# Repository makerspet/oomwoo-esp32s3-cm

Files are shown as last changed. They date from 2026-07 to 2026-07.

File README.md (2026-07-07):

# oomwoo-esp32s3-cm

Spec TBD; Not decided if we need this or not.

Pi CM4/CM5-compatible Compute Module using ESP32-S3 instead of CPU

Purpose - cost reduced "educational" version of OOMWOO open-source vacuum cleaner
robot by replacing Pi CM4/CM5 with ESP32-S3, moving mapping/navigation compute to
a separate local PC running ROS2.

Tradeoffs:
- this is not a "consumer product" anymore due to the need to set up the additional ROS2 local PC
  - PC-to-ESP32-S3 Wi-Fi connection can suffer from dead reception zones, busy Wi-Fi
- no camera-based obstacle recognition

- mounts on [OOMWOO carrier I/O board](https://github.com/makerspet/oomwoo-io-board)
- pin-compatible CM4/CM5 Compute Module using ESP32-S3 (instead of CPU)
- expose GPIOs on CM4/CM5 headers
  - 1x serial to MCU
  - GPIOs (MCU acts as watchdog for ESP32-S3, can reset it if ESP32-S3 is unresponsive)
  - SPI (to IMU on I/O board)
  - I2C
  - 1x serial to LiDAR (via I/O board)
- Problem - no cameras, ESP32-S3 supports DVP parallel only, not MIPI

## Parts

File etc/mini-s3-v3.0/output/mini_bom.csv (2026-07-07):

Comment | Designator | Footprint | LCSC Part Number
0603B151K500NT | C14,C15,C16,C17,C26,C37 | C0603 | C1594
SS8050_C2150 | Q2,Q3 | SOT-23-3_L2.9-W1.3-P1.90-LS2.4-BR | C2150
KT-0603R | LED1 | LED0603-RD | C2286
KT-0603W | LED2 | LED0603-R-RD_WHITE | C2290
AMS1117-3.3 | U8 | SOT-223-3_L6.5-W3.4-P2.30-LS7.0-BR | C6186
CC0603KRX7R9BB104 | C1,C3,C18,C19,C21,C22,C23,C27 | C0603 | C14663
AO3401A | Q1 | SOT-23_L2.9-W1.3-P1.90-LS2.4-BR | C15127
CL10B223KB8NNNC | C10,C11 | C0603 | C21122
0603WAF0000T5E | R31,R32 | R0603 | C21189
0603WAF1000T5E | R3 | R0603 | C22775
0603WAF2702T5E | R6 | R0603 | C22967
0603WAF5100T5E | R1,R2,R10,R18,R19,R22,R23,R26,R27,R28,R30 | R0603 | C23193
0603WAF9102T5E | R15 | R0603 | C23265
0603WAF1002T5E | R4,R5,R7,R8,R9,R11,R12,R20,R21,R24,R25,R29,R40 | R0603 | C25804
0603WAF1103T5E | R13,R16,R17 | R0603 | C25805
CL21A226MAQNNNE | C8,C12 | C0805 | C45783
CL10A226MP8NUNE | C2,C4,C7,C9,C13,C24,C25 | C0603 | C86295
MT2492 | U4,U5 | SOT-23-6_L2.9-W1.6-P0.95-LS2.8-BL | C89358
ZH1.5-6A M | J4,J7 | CONN-TH_6P-P1.50_ZH1.5-6A | C146013
FNR4030S100MT | L1,L2 | IND-SMD_L4.0-W4.0_FNR40XXS | C167879
1N5819WS | D1,D2,D3 | SOD-323_L1.8-W1.3-LS2.5-RD | C191023
TS-1187A-B-A-B | SW2,SW3 | SW-SMD_4P-L5.1-W5.1-P3.70-LS6.5-TL-2 | C318884
AECR0603F15K0K9 | R14 | R0603 | C328339
SK12D07VG5 | SW1 | SW-TH_SK12D07VG5 | C431548
ESP32-S3-WROOM-1-N4 | U3 | WIFIM-SMD_ESP32-S3-WROOM-1-N8 | C2913197
USB-MR-D-015 | U7,U9 | MICRO-USB-SMD_920-C52A2021S10105 | C2926986
BDR6120H | U1,U2 | SOP-8_L4.9-W3.8-P1.27-LS6.0-BL | C3007876
1.25-4PLTDK | J13 | CONN-SMD_4P-P1.25_SHOU_1.25-4PLTDK | C3008549
MX250-3.5-02P-B-GY01-CU-A | J2 | CONN-TH_2P-MX250-3.5-02P-B-GY01-CU-A | C7470116
CH340K_C18208922 | U6 | ESOP-10_L4.9-W3.9-P1.00-LS6.0-BL-EP | C18208922

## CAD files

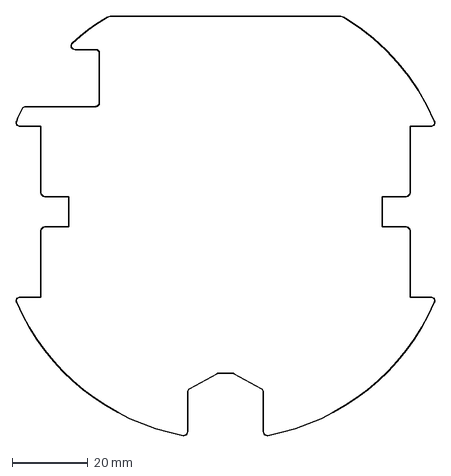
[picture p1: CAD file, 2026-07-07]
etc/mini-s3-v3.0/pcb_cutout.dxf
110.3 x 110.5 mm

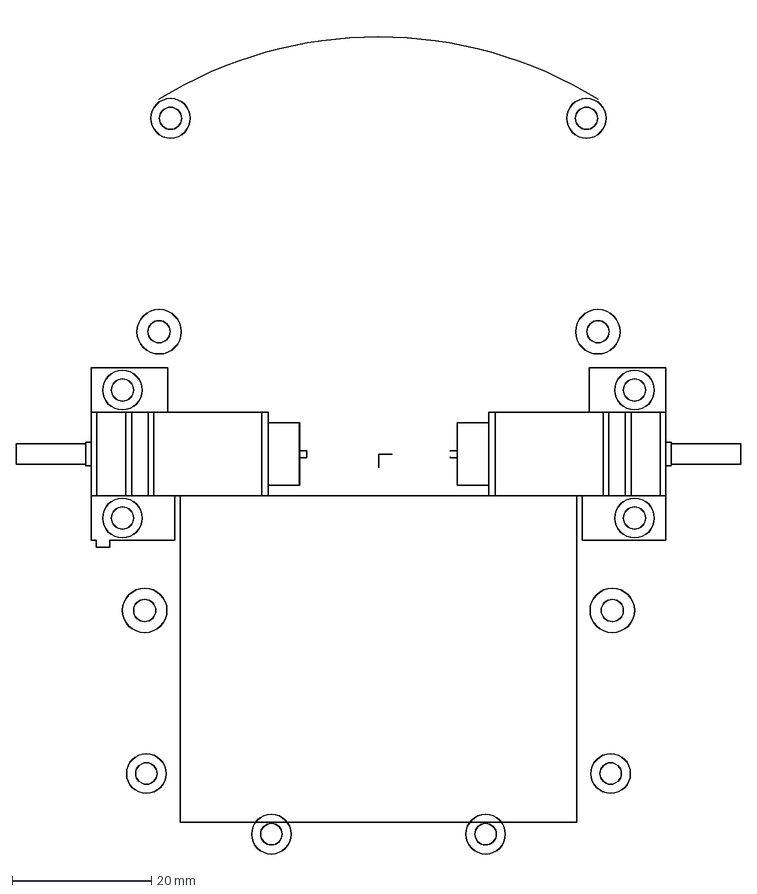
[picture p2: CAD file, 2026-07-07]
etc/mini-s3-v3.0/pcb_placement.dxf
104.2 x 120.5 mm

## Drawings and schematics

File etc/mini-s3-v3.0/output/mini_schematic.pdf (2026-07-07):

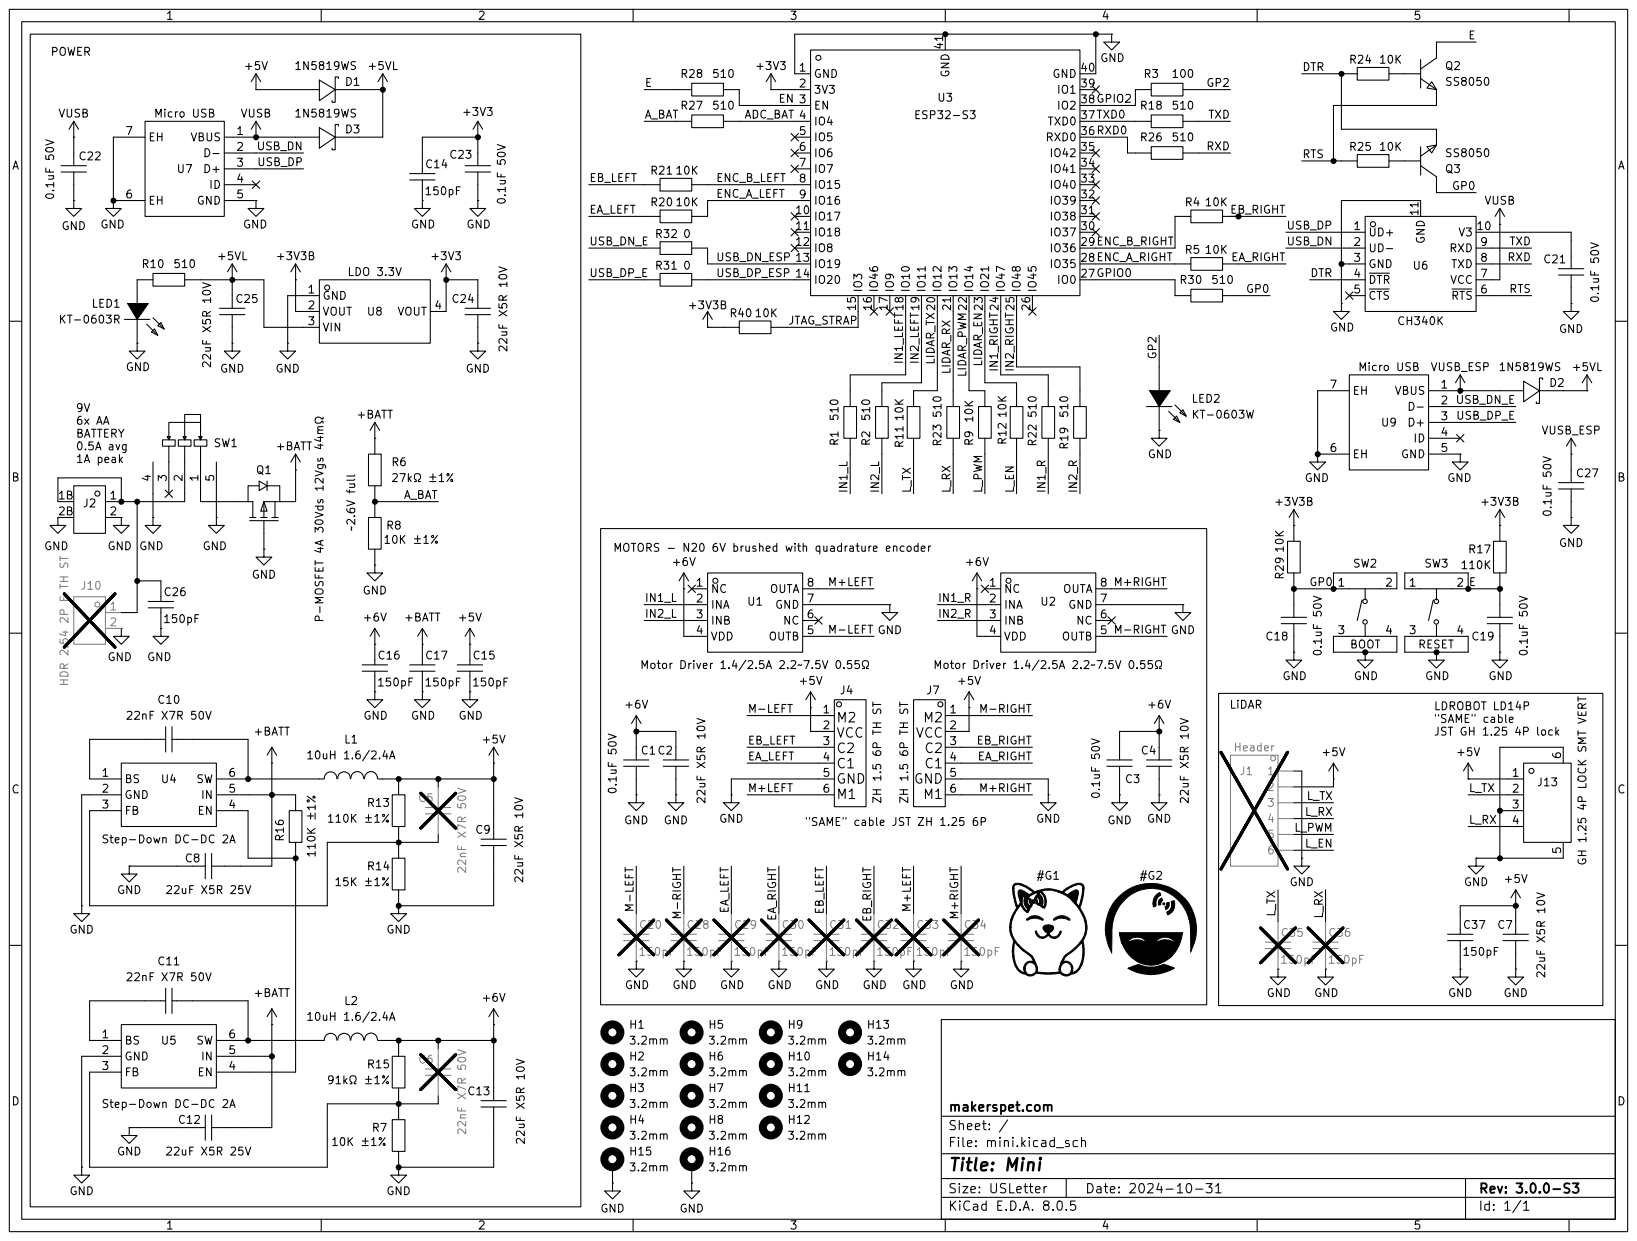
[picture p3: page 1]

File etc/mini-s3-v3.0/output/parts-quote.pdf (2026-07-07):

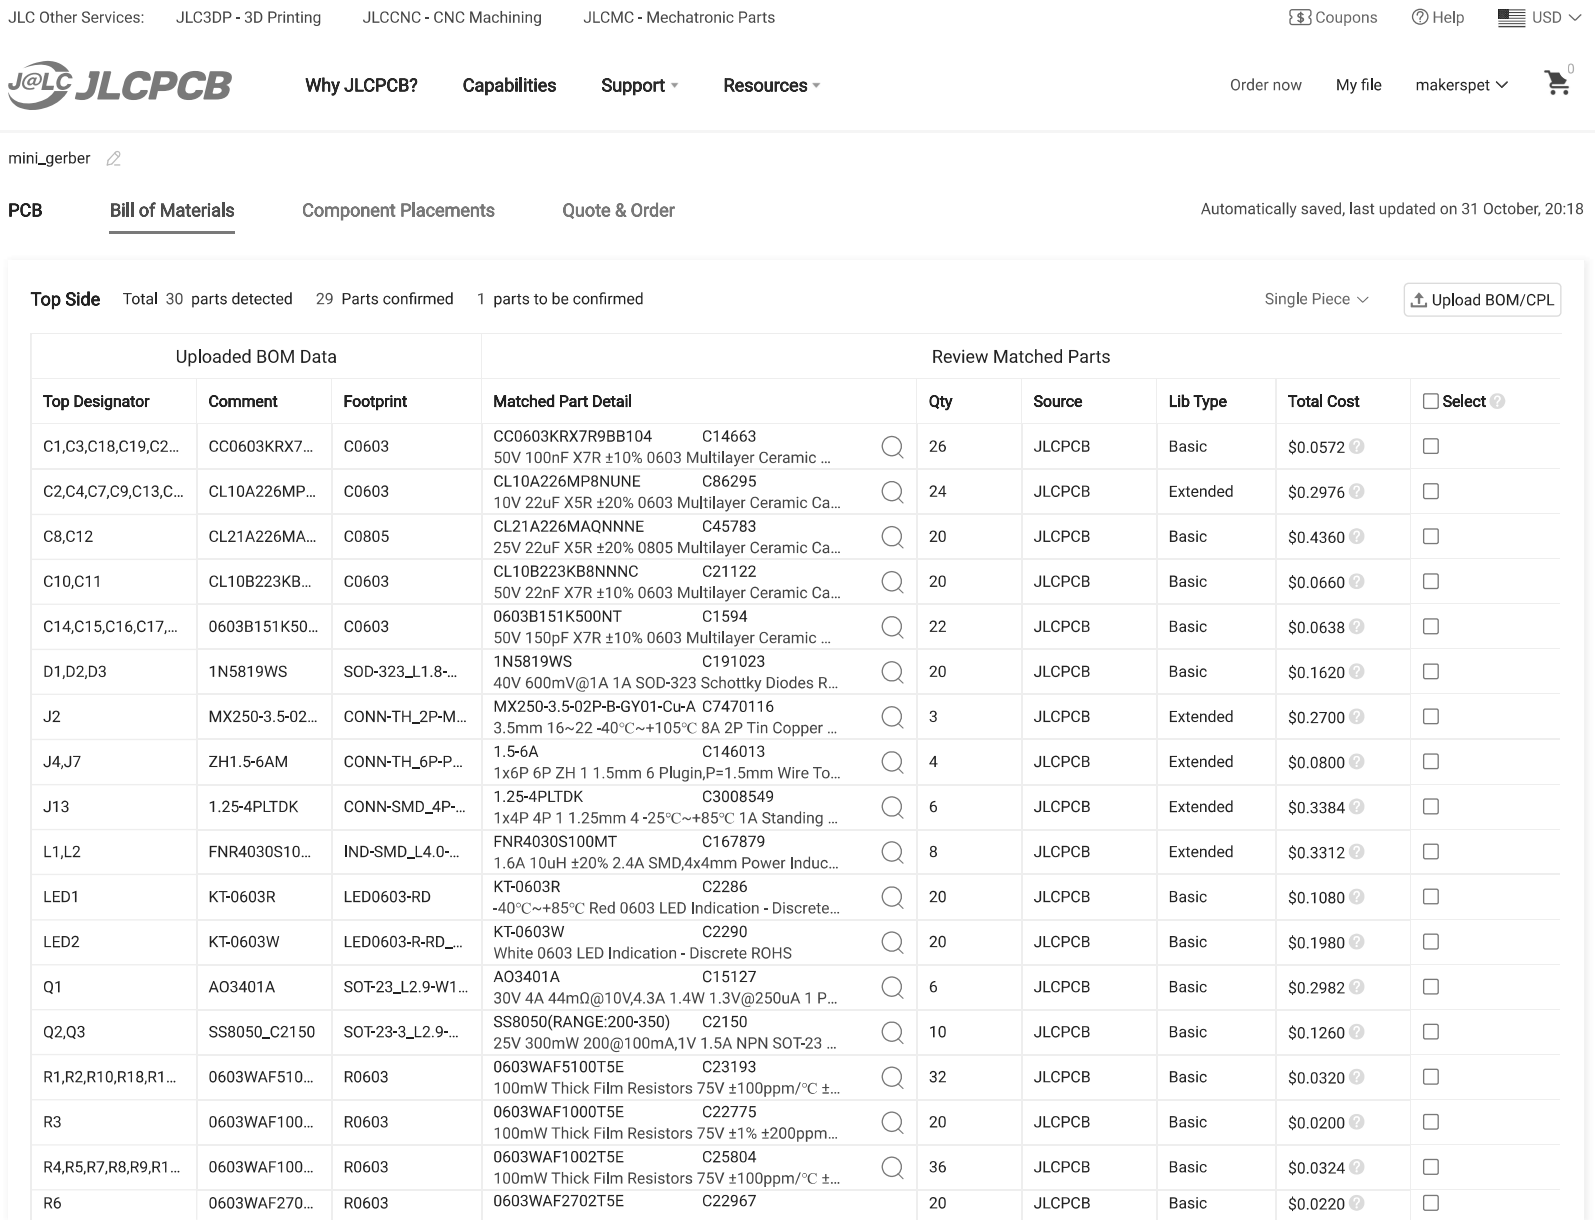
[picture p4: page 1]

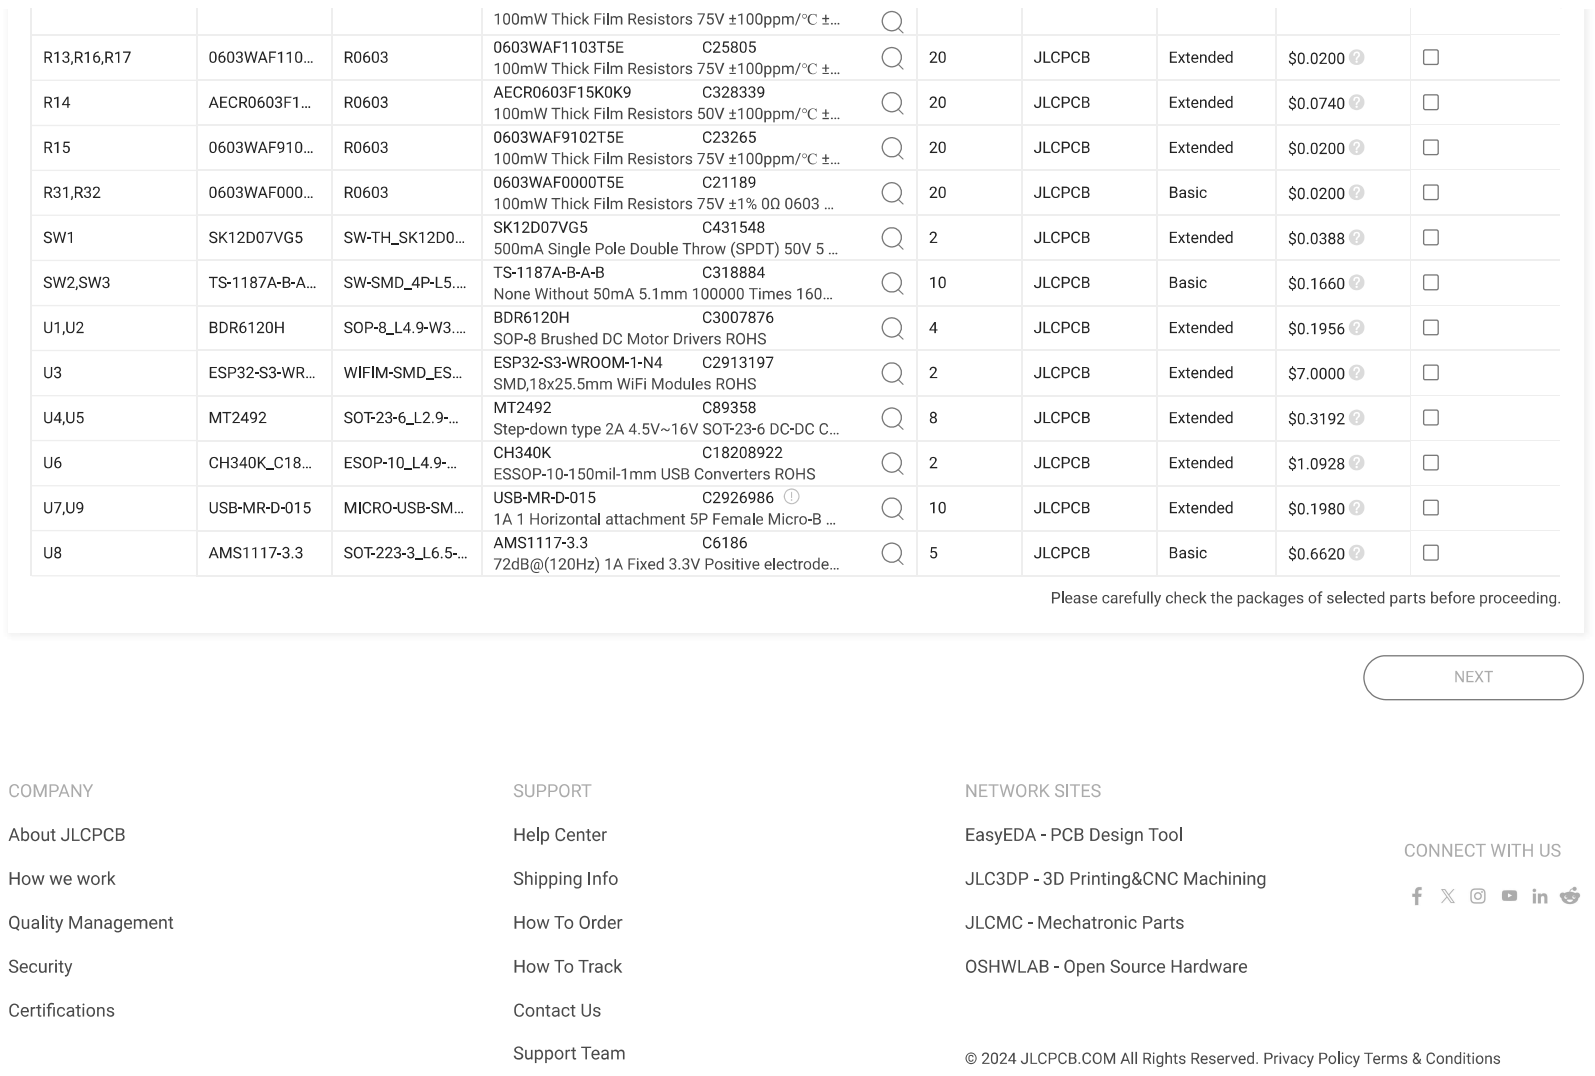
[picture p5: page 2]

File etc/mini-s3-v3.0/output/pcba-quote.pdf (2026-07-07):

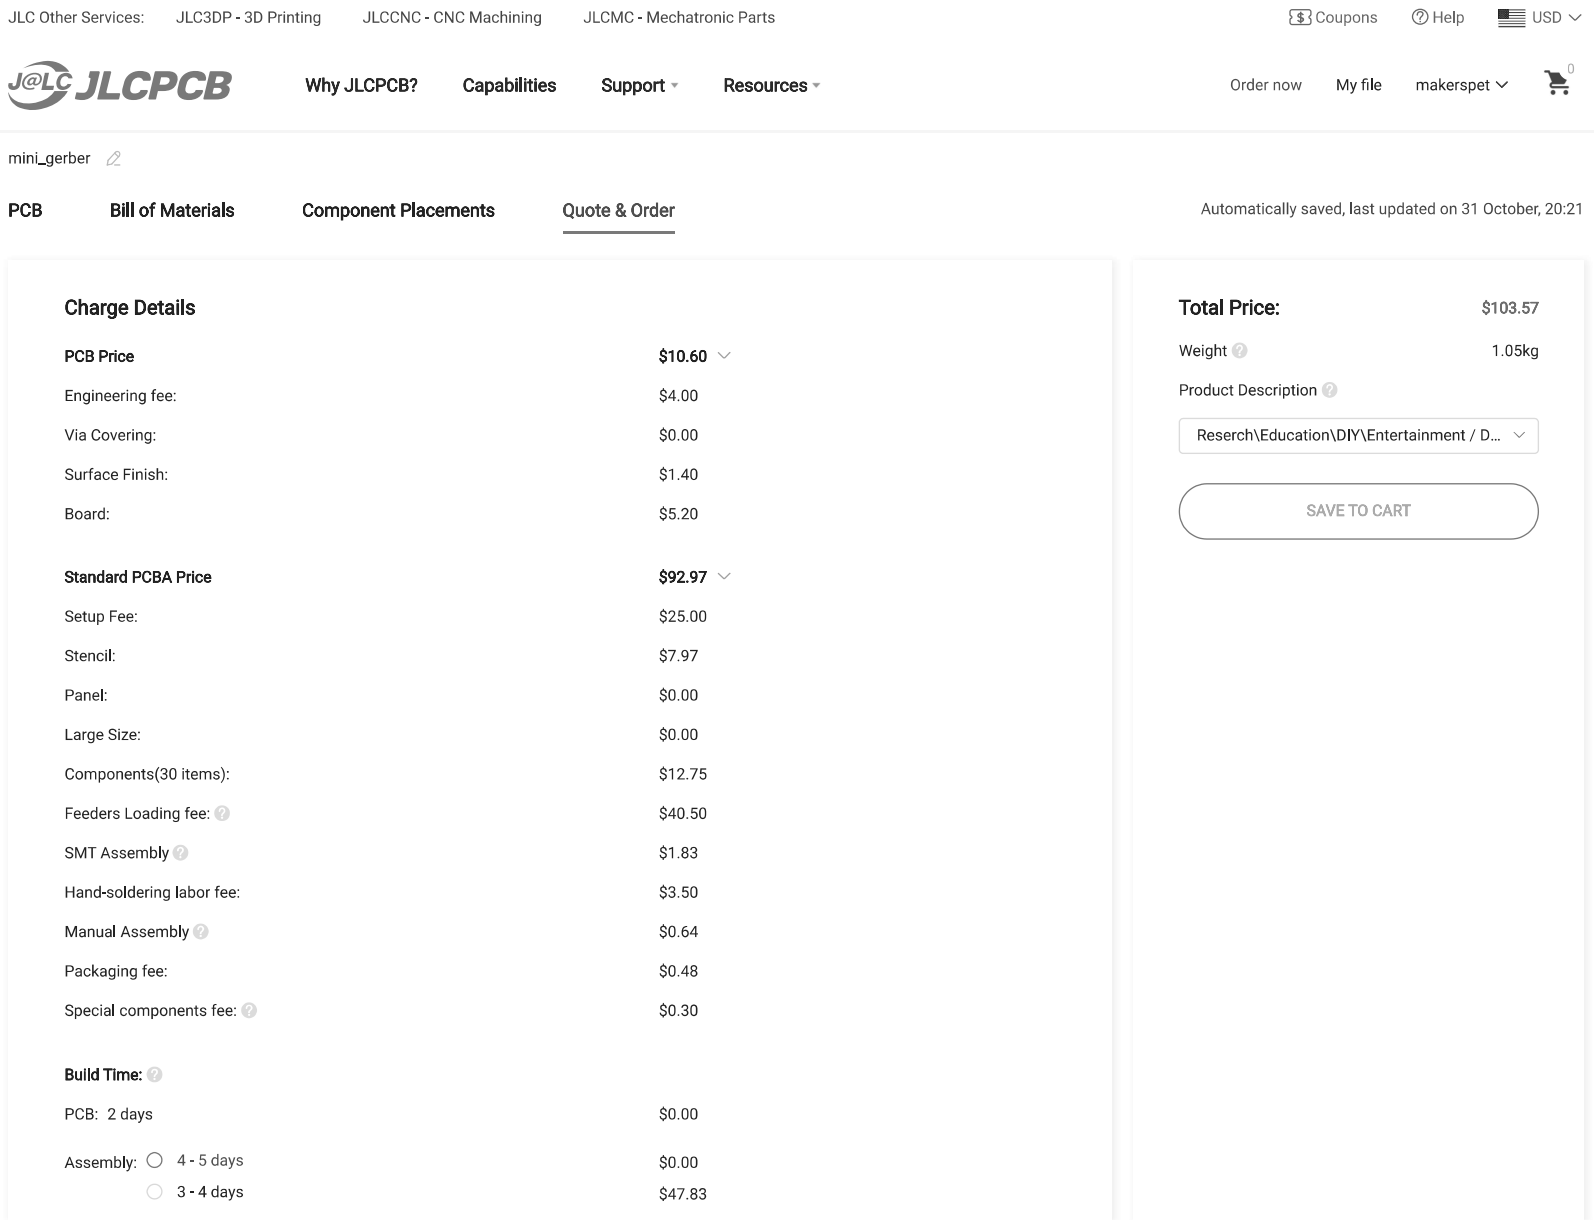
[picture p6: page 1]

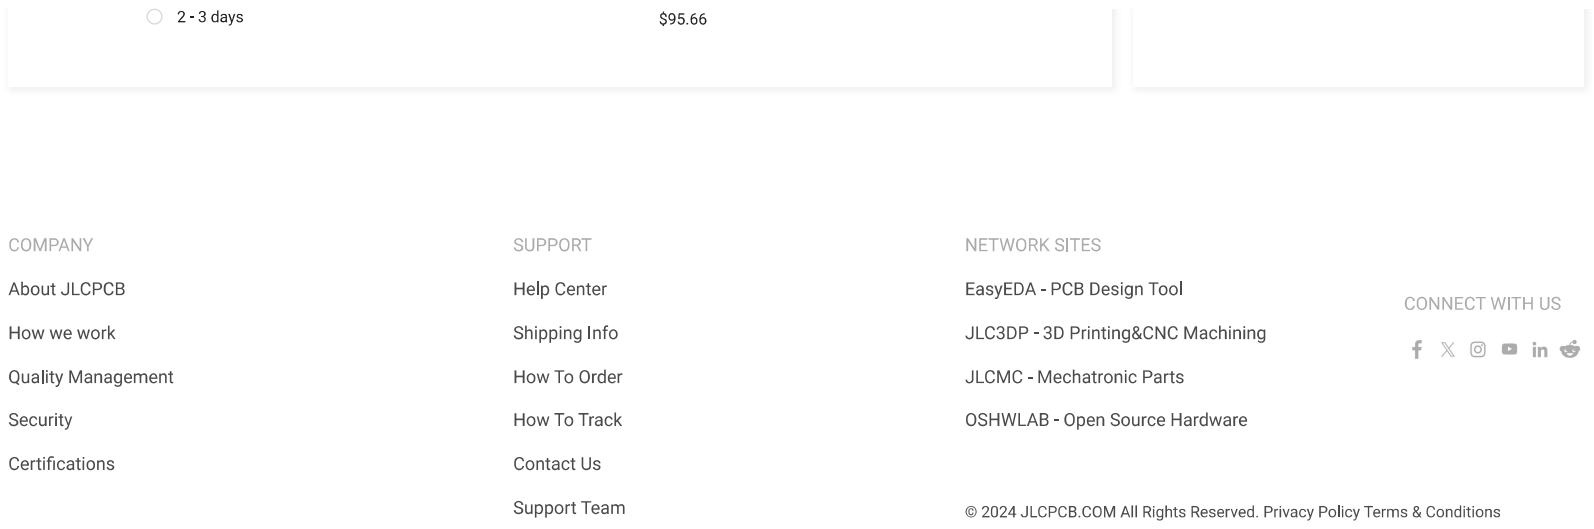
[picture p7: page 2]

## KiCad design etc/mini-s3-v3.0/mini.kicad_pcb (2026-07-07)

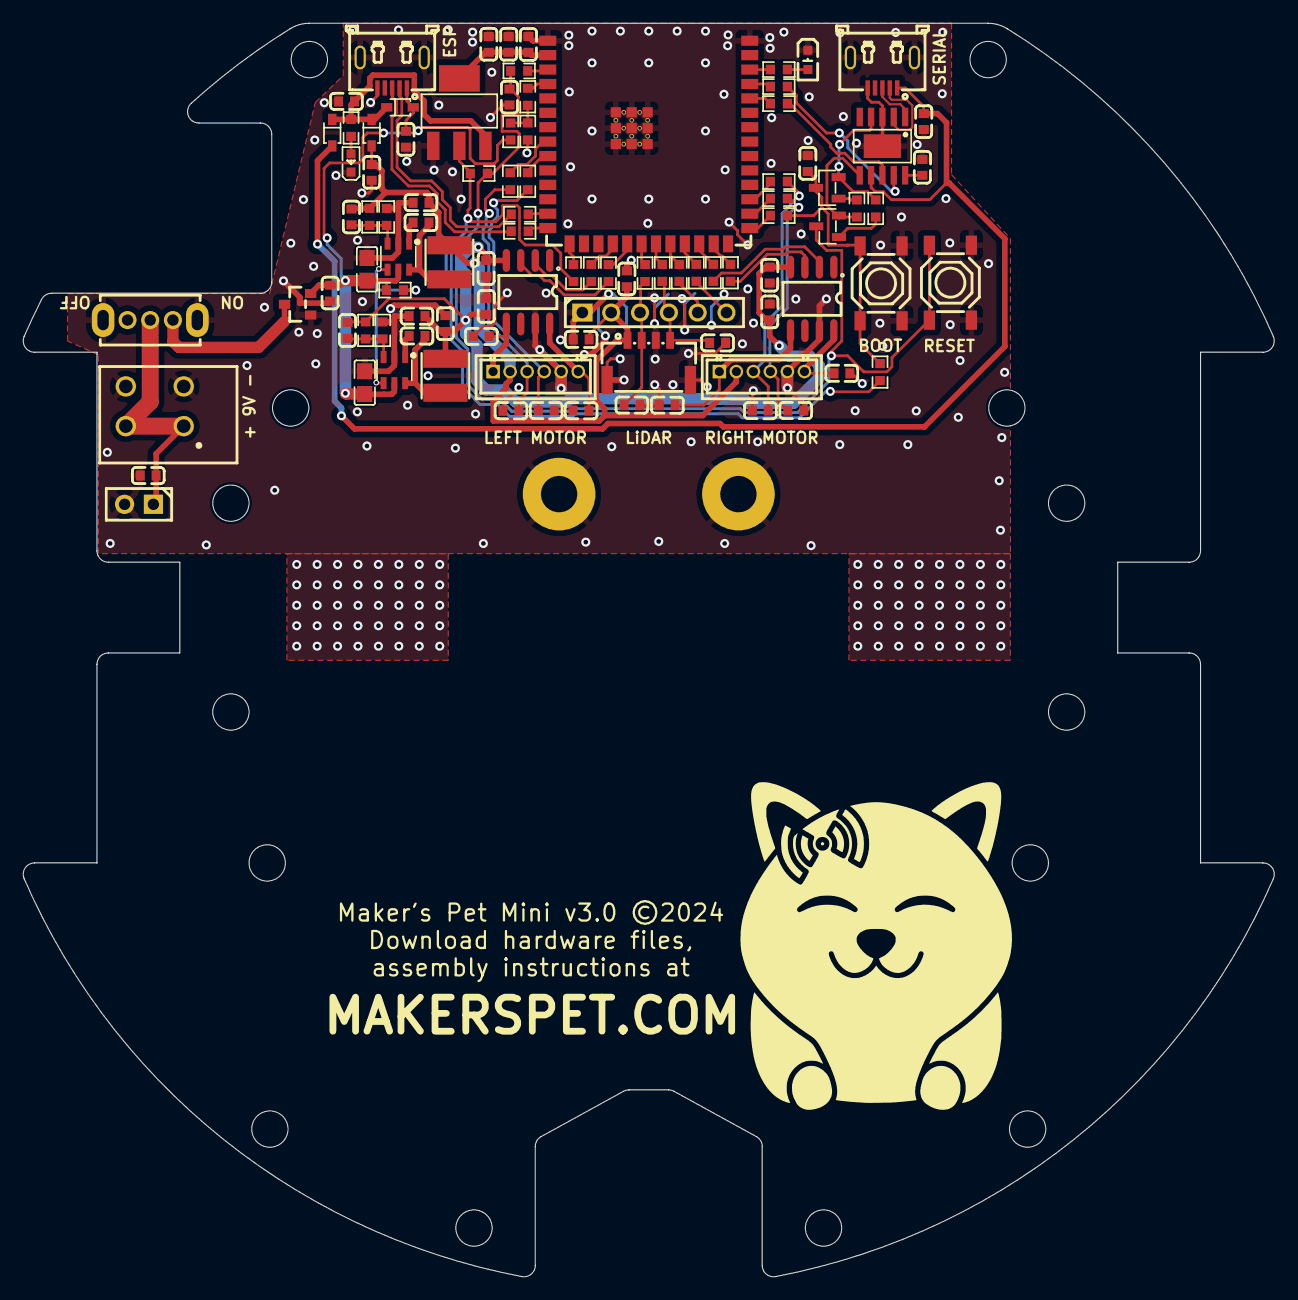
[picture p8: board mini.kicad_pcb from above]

Board: 2 copper layers, 110.2 x 110.5 mm, 114 parts (0 on the bottom side), 71 nets.

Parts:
C1, C3, C18, C19, C21, C22, C23, C27: CC0603KRX7R9BB104; C0603
C2, C4, C7, C9, C13, C24, C25: CL10A226MP8NUNE; C0603
C5, C6, C10, C11: CL10B223KB8NNNC; C0603
C8, C12: CL21A226MAQNNNE; C0805
C14, C15, C16, C17, C20, C26, C28, C29, C30, C31, C32, C33, C34, C35, C36, C37: 0603B151K500NT; C0603
D1, D2, D3: 1N5819WS; SOD-323_L1.8-W1.3-LS2.5-RD
H1, H2, H3, H4, H5, H6, H7, H8, H9, H10, H11, H12, H13, H14: 3.2mm; MountingHole_3.2mm_M3
H15, H16: 3.2mm; MountingHole_3.2mm_M3_Pad
J1: 2685Y-106CNG1SNA01; HDR-TH_6P-P2.54-V-F
J2: MX250-3.5-02P-B-GY01-CU-A; CONN-TH_2P-MX250-3.5-02P-B-GY01-CU-A
J4, J7: ZH1.5-6A M; CONN-TH_6P-P1.50_ZH1.5-6A
J10: 22850102ANG1SYA02; HDR-TH_2P-P2.54-V-F
J13: 1.25-4PLTDK; CONN-SMD_4P-P1.25_SHOU_1.25-4PLTDK
L1, L2: FNR4030S100MT; IND-SMD_L4.0-W4.0_FNR40XXS
LED1: KT-0603R; LED0603-RD
LED2: KT-0603W; LED0603-R-RD_WHITE
Q1: AO3401A; SOT-23_L2.9-W1.3-P1.90-LS2.4-BR
Q2, Q3: SS8050_C2150; SOT-23-3_L2.9-W1.3-P1.90-LS2.4-BR
R1, R2, R10, R18, R19, R22, R23, R26, R27, R28, R30: 0603WAF5100T5E; R0603
R3: 0603WAF1000T5E; R0603
R4, R5, R7, R8, R9, R11, R12, R20, R21, R24, R25, R29, R40: 0603WAF1002T5E; R0603
R6: 0603WAF2702T5E; R0603
R13, R16, R17: 0603WAF1103T5E; R0603
R14: AECR0603F15K0K9; R0603
R15: 0603WAF9102T5E; R0603
R31, R32: 0603WAF0000T5E; R0603
SW1: SK12D07VG5; SW-TH_SK12D07VG5
SW2, SW3: TS-1187A-B-A-B; SW-SMD_4P-L5.1-W5.1-P3.70-LS6.5-TL-2
U1, U2: BDR6120H; SOP-8_L4.9-W3.8-P1.27-LS6.0-BL
U3: ESP32-S3-WROOM-1-N4; WIFIM-SMD_ESP32-S3-WROOM-1-N8
U4, U5: MT2492; SOT-23-6_L2.9-W1.6-P0.95-LS2.8-BL
U6: CH340K_C18208922; ESOP-10_L4.9-W3.9-P1.00-LS6.0-BL-EP
U7, U9: USB-MR-D-015; MICRO-USB-SMD_920-C52A2021S10105
U8: AMS1117-3.3; SOT-223-3_L6.5-W3.4-P2.30-LS7.0-BR

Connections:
+3V3: C14.1, C23.2, C24.2, U3.2 (3V3), U8.4 (VOUT)
+3V3B: R17.2, R29.2, R40.2, U8.2 (VOUT)
+5V: C5.2, C7.2, C9.2, C15.1, C37.1, D1.2 (A), J1.2, J4.2, J7.2, J13.1, L1.2, R13.2
+5VL: C25.2, D1.1 (K), D2.1 (K), D3.1 (K), R10.2, U8.3 (VIN)
+6V: C1.2, C2.2, C3.2, C4.2, C6.2, C13.2, C16.1, L2.2, R15.2, U1.4 (VDD), U2.4 (VDD)
+BATT: C8.2, C12.2, C17.1, Q1.2 (S), R6.2, R16.1, U4.5 (IN), U5.5 (IN)
/ADC_BAT: R27.2, U3.4 (IO4)
/A_BAT: R6.1, R8.2, R27.1
/DTR: Q3.2 (E), R24.1, U6.4 (~DTR)
/E: C19.2, Q2.3 (C), R17.1, R28.1, SW3.1 (A), SW3.2 (B)
/EA_LEFT: C29.1, J4.4, R20.2
/EA_RIGHT: C30.1, J7.4, R5.2
/EB_LEFT: C31.1, J4.3, R21.2
/EB_RIGHT: C32.1, J7.3, R4.2
/EN: R28.2, U3.3 (EN)
/ENC_A_LEFT: R20.1, U3.9 (IO16)
/ENC_A_RIGHT: R5.1, U3.28 (IO35)
/ENC_B_LEFT: R21.1, U3.8 (IO15)
/ENC_B_RIGHT: R4.1, U3.29 (IO36)
/GP0: C18.2, Q3.3 (C), R29.1, R30.2, SW2.1 (A), SW2.2 (B)
/GP2: LED2.1 (A), R3.2
/GPIO0: R30.1, U3.27 (IO0)
/GPIO2: R3.1, U3.38 (IO2)
/IN1_L: R1.1, U1.2 (INA)
/IN1_LEFT: R1.2, U3.18 (IO10)
/IN1_R: R22.1, U2.2 (INA)
/IN1_RIGHT: R22.2, U3.24 (IO47)
/IN2_L: R2.1, U1.3 (INB)
/IN2_LEFT: R2.2, U3.19 (IO11)
/IN2_R: R19.1, U2.3 (INB)
/IN2_RIGHT: R19.2, U3.25 (IO48)
/JTAG_STRAP: R40.1, U3.15 (IO3)
/LIDAR_EN: R12.2, U3.23 (IO21)
/LIDAR_PWM: R9.2, U3.22 (IO14)
/LIDAR_RX: R23.2, U3.21 (IO13)
/LIDAR_TX: R11.2, U3.20 (IO12)
/L_EN: J1.6, R12.1
/L_PWM: J1.5, R9.1
/L_RX: C36.1, J1.4, J13.4, R23.1
/L_TX: C35.1, J1.3, J13.2, R11.1
/M+LEFT: C33.1, J4.6, U1.8 (OUTA)
/M+RIGHT: C34.1, J7.6, U2.8 (OUTA)
/M-LEFT: C20.1, J4.1, U1.5 (OUTB)
/M-RIGHT: C28.1, J7.1, U2.5 (OUTB)
/RTS: Q2.2 (E), R25.1, U6.6 (~RTS)
/RXD: R26.2, U6.8 (TXD)
/RXD0: R26.1, U3.36 (RXD0)
/TXD: R18.2, U6.9 (RXD)
/TXD0: R18.1, U3.37 (TXD0)
/USB_DN: U6.2 (UD-), U7.2 (D-)
/USB_DN_E: R32.1, U9.2 (D-)
/USB_DN_ESP: R32.2, U3.13 (IO19)
/USB_DP: U6.1 (UD+), U7.3 (D+)
/USB_DP_E: R31.1, U9.3 (D+)
/USB_DP_ESP: R31.2, U3.14 (IO20)
GND: C1.1, C2.1, C3.1, C4.1, C7.1, C8.1, C9.1, C12.1, C13.1, C14.2, C15.2, C16.2, C17.2, C18.1, C19.1, C20.2, C21.1, C22.1, C23.1, C24.1, C25.1, C26.2, C27.1, C28.2, C29.2, C30.2, C31.2, C32.2, C33.2, C34.2, C35.2, C36.2, C37.2, H15.1, H16.1, J1.1, J2.2, J2.2B, J4.5, J7.5, J10.2, J13.3, J13.5, J13.6, LED1.1 (K), LED2.2 (K), Q1.1 (G), R7.1, R8.1, R14.1, SW1.4, SW1.5, SW2.3 (C), SW2.4 (D), SW3.3 (C), SW3.4 (D), U1.7 (GND), U2.7 (GND), U3.1 (GND), U3.40 (GND), U3.41 (GND), U4.2 (GND), U5.2 (GND), U6.3 (GND), U6.11 (GND), U7.5 (GND), U7.6 (EH), U7.7 (EH), U8.1 (GND), U9.5 (GND), U9.6 (EH), U9.7 (EH)
unnamed: C26.1, J2.1, J2.1B, J10.1, SW1.2
unnamed: LED1.2 (A), R10.1
unnamed: Q1.3 (D), SW1.1
unnamed: Q2.1 (B), R24.2
unnamed: Q3.1 (B), R25.2
unnamed: C10.1, U4.1 (BS)
unnamed: R16.2, U4.4 (EN), U5.4 (EN)
unnamed: C5.1, R13.1, R14.2, U4.3 (FB)
unnamed: C10.2, L1.1, U4.6 (SW)
unnamed: C11.1, U5.1 (BS)
unnamed: C6.1, R7.2, R15.1, U5.3 (FB)
unnamed: C11.2, L2.1, U5.6 (SW)
unnamed: C21.2, U6.10 (V3)
VUSB: C22.2, D3.2 (A), U6.7 (VCC), U7.1 (VBUS)
VUSB_ESP: C27.2, D2.2 (A), U9.1 (VBUS)

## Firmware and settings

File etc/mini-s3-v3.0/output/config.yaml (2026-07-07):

#
# Board-specific assignments
#
board:
  manufacturer: makerspet.com
  model: MINI-S3
  version: v3.0.0
lidar:
  gpio:
    tx: 12
    rx: 13
    pwm: 14
    en: 21
led:
  system: 
    gpio: 2
    invert: false
button:
  boot:
    gpio: 0
    invert: true
monitor:
  gpio:
    tx: 43
motor:
  driver:
    type: IN1_IN2
  encoder:
    type: AB_QUAD
  left:
    encoder:
      gpio:
        a: 16
        b: 15
    driver:
      gpio:
        in1: 10
        in2: 11
  right:
    encoder:
      gpio:
        a: 35
        b: 36
    driver:
      gpio:
        in1: 47
        in2: 48
adc:
  battery:
    attenuation: 3.7
    gpio: 4
    voltage:
# 6V motors, 6x AA/D/C (1.2-1.6V) batteries
      full: 9.9
      empty: 7.2

#
# Peripherals configuration
#
lidar:
  model: LDROBOT LD14P
# model: NEATO XV11
# model: SLAMTEC RPLIDAR A1
# model: XIAOMI LDS02RR
# model: YDLIDAR SCL
# model: YDLIDAR X2
# model: YDLIDAR X2L
# model: YDLIDAR X3
# model: YDLIDAR X3 PRO
# model: 3IROBOTIX DELTA-2G
# model: 3IROBOTIX DELTA-2A 115200
# model: 3IROBOTIX DELTA-2A
# model: 3IROBOTIX DELTA-2B
# model: YDLIDAR X4 PRO
# model: YDLIDAR X4
  scan:
    freq:
      target: 5.0
monitor:
  baud: 115200
base:
  wheel:
    track: 0.105043
    diameter: 0.043
    accel:
      max: 2.0
motor:
  rpm:
# derated
    max: 180
  driver:
    pid:
      period: 0.03
      kp: 0.001
      ki: 0.003
      kd: 0
      kpm: 0
  encoder:
    ppr: 1035
  left:
    encoder:
      reverse: true
    driver:
      reverse: true
  right:
    encoder:
      reverse: true
    driver:
      reverse: true

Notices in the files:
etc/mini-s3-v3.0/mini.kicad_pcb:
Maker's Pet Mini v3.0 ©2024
